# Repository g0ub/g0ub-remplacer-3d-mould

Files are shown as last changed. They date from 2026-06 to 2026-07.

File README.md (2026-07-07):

# REMPLACER — Agarose Mouse Brain Mould / Moule cerveau de souris en agarose

<p align="center">
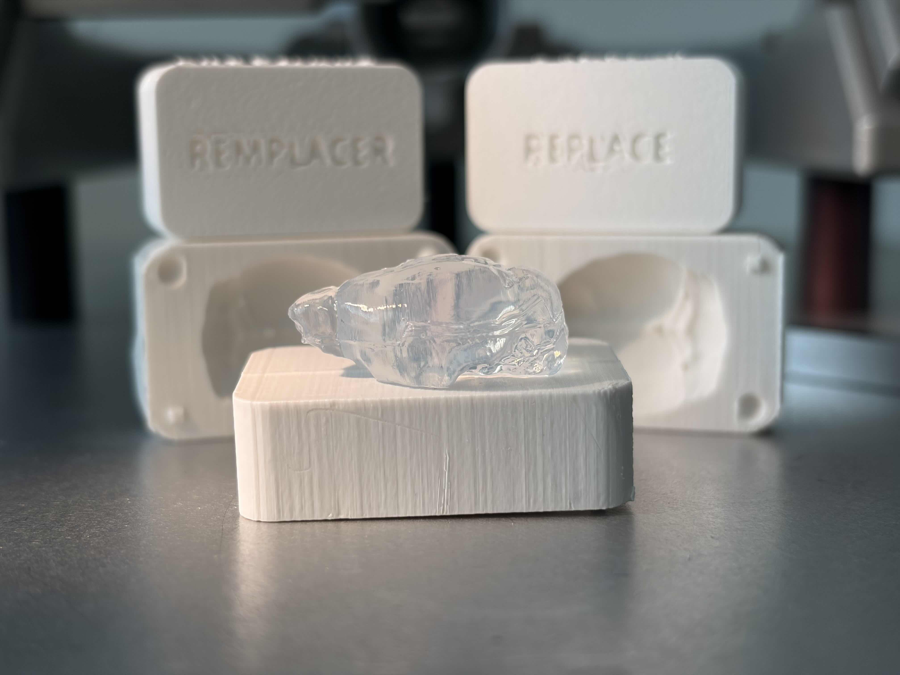
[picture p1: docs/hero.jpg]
REMPLACER / REPLACE printed mould halves with a freshly cast translucent agarose mouse brain in the foreground
  
</p>

**FR** | [EN below](#english-version)

---

## Version française

Ce dépôt contient les fichiers d'un moule en deux parties permettant de fabriquer des cerveaux de souris en **agarose**, utilisés dans l'atelier de médiation scientifique **REMPLACER** depuis 2017.

Le moule a été conçu à partir de **données anatomiques réelles de souris, librement accessibles en ligne**, et d'un générateur de moule paramétrique open source (voir [Sources & crédits](#sources--crédits)). Il permet de produire un modèle translucide utilisable avec un cadre stéréotaxique standard, **sans utiliser aucun animal**.

### ⬇️ Télécharger les moules

Fichiers STL prêts à imprimer (téléchargement direct) :

- **[Moule ×1,5](https://github.com/g0ub/g0ub-remplacer-3d-mould/releases/download/v1.0/mould_x1_5.stl)** — cerveau de souris adulte (~24 mm)
- **[Moule ×1,75](https://github.com/g0ub/g0ub-remplacer-3d-mould/releases/download/v1.0/mould_x1_75.stl)** — souris large / rat juvénile (~28 mm)
- **[Moule ×3](https://github.com/g0ub/g0ub-remplacer-3d-mould/releases/download/v1.0/mould_x3.stl)** — version atelier, braille tactile

Toutes les versions sont réunies sur la [page des releases](https://github.com/g0ub/g0ub-remplacer-3d-mould/releases). Pour explorer, modifier ou forker les fichiers source, voir le dossier [`/stl`](stl/) et le générateur OpenSCAD ([`scad/`](scad/)).

### 🙋 Vous avez utilisé ce moule ? Partagez vos retours !

Vous avez fabriqué des cerveaux en agarose pour votre labo, vos TP ou un atelier de médiation ? **Partagez votre expérience en ouvrant une [Issue](../../issues) sur ce dépôt** — photos, adaptations, retours de publics, versions modifiées du moule : tout est bienvenu. Si c'est plus simple, vous pouvez aussi écrire directement à : philippe.zizzari@inserm.fr.

Ces retours nous aident à améliorer le dispositif et à documenter son impact. Ils sont aussi précieux pour convaincre nos institutions de continuer à soutenir ce type de projet 🙂

> 🛠️ Si vous adaptez le moule, **merci de forker ce dépôt** plutôt que de redistribuer les fichiers séparément — cela préserve la traçabilité et permet à tout le monde de bénéficier des améliorations.

### Contenu du dépôt

```
/scad/
    mould_remplacer.scad   — source paramétrique (en-tête d'attribution inclus)
    mold_file.stl          — STL du cerveau aligné (importé par le .scad)
/stl/
    mould_x1_5.stl         — moule à ×1.5 (cerveau de souris adulte ~24 mm)
    mould_x1_75.stl        — moule à ×1.75 (souris large / rat juvénile ~28 mm)
    mould_x3.stl           — moule à ×3 (version atelier, braille tactile lisible)
/brain/
    README.md              — lien NITRC + notes de conversion .nii → STL (VTK)
/scripts/
    align_stl.py           — réoriente automatiquement un STL exporté de Slicer
PROTOCOL.md                — protocole de fabrication des cerveaux en agarose
CREDITS.md                 — attributions complètes (cerveau, Webb, rocketboy)
LICENSE                    — licence CC BY-NC-SA 4.0
```

> Le fichier de cerveau d'origine (`.nii`) **n'est pas redistribué ici**. En revanche, le STL pré-aligné (`/scad/mold_file.stl`) est inclus pour que le `.scad` compile directement après le clone — c'est aussi un dérivé du template NITRC, autorisé par sa licence CC BY-NC-SA. Voir le dossier [`/brain/`](brain/) si tu veux **régénérer** le STL depuis le `.nii` (par exemple pour un autre template, une autre espèce, ou pour adapter la résolution du maillage). Dans ce cas, fais-le passer par [`scripts/align_stl.py`](scripts/align_stl.py) avant de l'utiliser dans le `.scad` (voir [`brain/README.md`](brain/README.md) §3).

### Protocole rapide

1. Imprimer les deux parties du moule (PLA, résolution 0.2 mm recommandée)
2. Préparer une solution d'agarose à 1 à 2 % dans de l'eau distillée (1 % donne plus de translucidité, 2 % plus de tenue). **Astuce pratique** : verser la poudre dans l'eau, remuer, passer **30 s au micro-ondes** — ça dissout nickel. ⚠️ Le bord du bécher devient brûlant.
3. Fermer le moule en scotchant les deux parties sur la tranche, puis ajouter des bandes de scotch à 90° pour assurer l'étanchéité ; couler l'agarose encore chaud
4. Laisser polymériser ~15 min à température ambiante, puis ≥20 min à 4 °C (à ajuster selon vos conditions — **attendre vraiment** la polymérisation complète, c'est ce qui détermine la réussite du démoulage)
5. Démouler délicatement

### Impression et réglage des gravures

**Impression** — PLA, résolution 0.2 mm, remplissage 15–20 %. Les deux moitiés peuvent être imprimées face arrière sur le plateau (face avec le texte) : le texte apparaît bien net sur la première couche. Des supports sont nécessaires pour le canal de coulée et le braille (cf. [`PROTOCOL.md`](PROTOCOL.md) pour la procédure de *support blocker* dans la cuvette).

**Réglage des gravures** — toutes les valeurs sont paramétrables en haut du fichier [`scad/mould_remplacer.scad`](scad/mould_remplacer.scad) (bloc *Engraving parameters*) :

| Paramètre | Défaut | Rôle |
|---|---|---|
| `text_depth` | 1.2 mm | profondeur de gravure du texte REMPLACER / REPLACE |
| `text_size` | 9 mm | hauteur des lettres |
| `text_mirror_top` / `text_mirror_bottom` | `false` / `true` | si le texte apparaît en miroir une fois la pièce retournée, inverse |
| `braille_dot_d` | 1.5 mm | diamètre du point au contact (lisibilité tactile) |
| `braille_dot_h` | 0.75 mm | **hauteur du point qui dépasse** — indépendante du diamètre |
| `braille_dot_dist` | 2.5 mm | espacement entre points d'une cellule (norme Marburg) |
| `braille_cell_pitch` | 6.0 mm | espacement entre cellules (norme Marburg) |

> Le standard Marburg français pour le braille est d ≈ 1.5 mm et h ≈ 0.5 mm. La valeur par défaut de `braille_dot_h` est volontairement un peu plus haute (0.75 mm) pour compenser l'écrasement d'un point en PLA à 0.2 mm de couche. À ajuster selon ton imprimante : descends vers 0.5 mm si tes points ressortent trop pointus, monte vers 1 mm si on les sent à peine.

### En usage / In use

<p align="center">
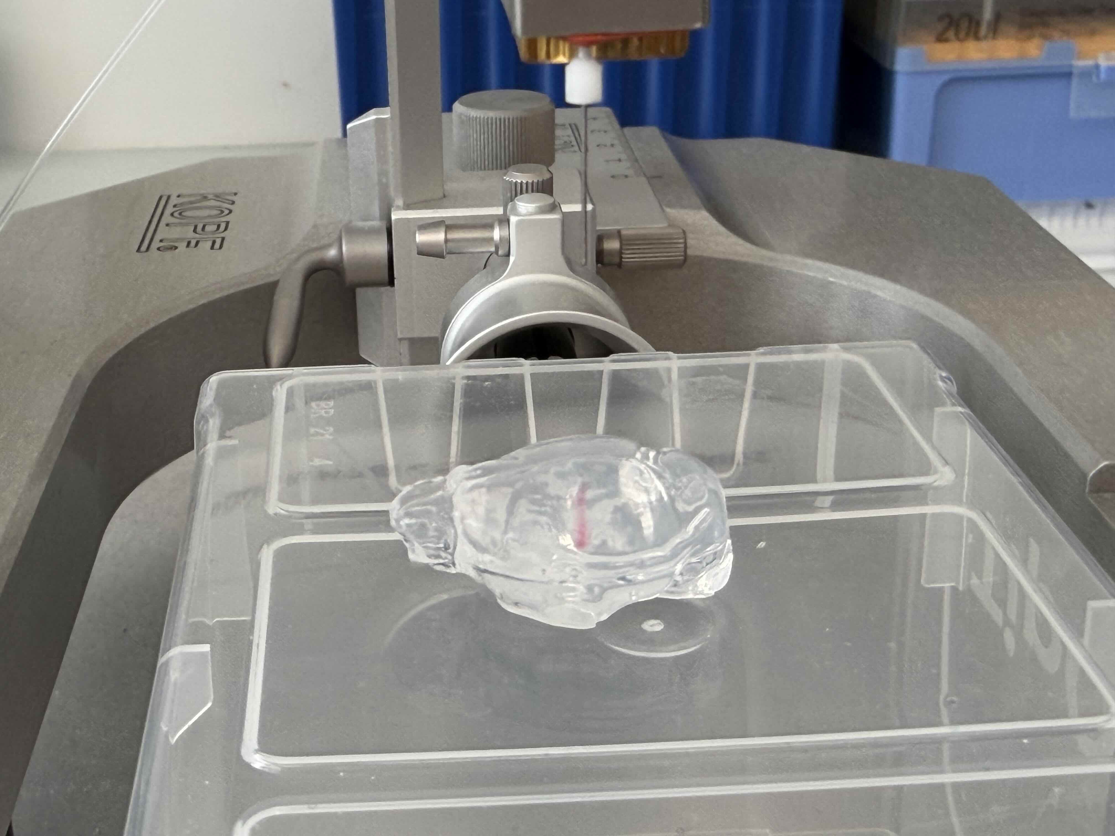
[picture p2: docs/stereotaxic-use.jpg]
Agarose mouse brain positioned in a Kopf stereotaxic frame with a visible injection trace inside the translucent gel
  
</p>

**🇫🇷** Cerveau en agarose moulé avec ce dispositif, positionné dans un cadre stéréotaxique standard. La trace rouge à l'intérieur du gel est une démonstration d'injection : le cerveau translucide permet de **voir en direct** la trajectoire de l'aiguille et le site de dépôt — un atout pédagogique central pour la formation en chirurgie stéréotaxique.

**🇬🇧** Agarose brain cast with this device, mounted in a standard stereotaxic frame. The red trace inside the gel is a demonstration injection: the translucent brain lets you **see in real time** the needle trajectory and the deposition site — a key teaching advantage for stereotaxic surgery training.

### Sources & crédits

Ce moule est un **travail dérivé**. Il réunit :

- le template anatomique de cerveau de souris C57BL/6 de **Hikishima et al. (2017)**, via NITRC (*tpm_mouse*), converti de NIfTI en STL ;
- le générateur de moule paramétrique en deux parties de **Jason Webb**, dans la version modifiée par **Dan Steele (rocketboy)** ;
- mes propres ajouts : positionnement du cerveau, canal de coulée oblique aligné sur le tronc cérébral, textes **REMPLACER / REPLACE** et leur transcription en **braille**.

La liste complète — liens, licences de chaque maillon et **citation à utiliser** — est dans [`CREDITS.md`](CREDITS.md). Merci de la conserver en cas de réutilisation.

### Licence

Ce travail est mis à disposition sous licence [Creative Commons Attribution — Pas d'Utilisation Commerciale — Partage dans les Mêmes Conditions 4.0 International (CC BY-NC-SA 4.0)](https://creativecommons.org/licenses/by-nc-sa/4.0/).

**En résumé :** vous pouvez utiliser, adapter et redistribuer ces fichiers librement, à condition de **citer les auteurs** (voir [`CREDITS.md`](CREDITS.md)), de **ne pas en faire un usage commercial**, et de **partager vos adaptations sous la même licence**.

Cette licence est imposée par le template de cerveau amont (CC BY-NC-SA) dont la géométrie est dérivée.

> 📝 **À titre personnel** — Ce dépôt et son contenu sont publiés à titre personnel par l'auteur. Les opinions, choix techniques et engagements qui y sont exprimés n'engagent que lui et ne reflètent pas nécessairement la position de l'INSERM ni de l'Université de Bordeaux. Les affiliations sont mentionnées à titre informatif uniquement.

**Auteur :** Philippe Zizzari — Ingénieur de Recherche, INSERM U1215, Neurocentre Magendie, Université de Bordeaux
**Contact :** philippe.zizzari@inserm.fr
**Site du projet :** [https://g0ub.github.io/remplacer/](https://g0ub.github.io/remplacer/)

---

## English version

This repository contains a two-part mould for casting **agarose** mouse brain models, used in the **REMPLACER** science outreach workshop since 2017.

The mould was designed from **real mouse anatomical data, freely available online**, together with an open-source parametric mould generator (see [Sources & credits](#sources--credits)). It produces a translucent model usable with a standard stereotaxic frame — **no animals required**.

### ⬇️ Download the moulds

Ready-to-print STL files (direct download):

- **[Mould ×1.5](https://github.com/g0ub/g0ub-remplacer-3d-mould/releases/download/v1.0/mould_x1_5.stl)** — adult mouse brain (~24 mm)
- **[Mould ×1.75](https://github.com/g0ub/g0ub-remplacer-3d-mould/releases/download/v1.0/mould_x1_75.stl)** — large mouse / juvenile rat (~28 mm)
- **[Mould ×3](https://github.com/g0ub/g0ub-remplacer-3d-mould/releases/download/v1.0/mould_x3.stl)** — workshop version, tactile braille

All versions are on the [releases page](https://github.com/g0ub/g0ub-remplacer-3d-mould/releases). To browse, modify or fork the source files, see the [`/stl`](stl/) folder and the OpenSCAD generator ([`scad/`](scad/)).

### 🙋 Have you used this mould? Share your feedback!

Have you cast agarose brains for your lab, teaching practicals, or an outreach event? **Open an [Issue](../../issues) to share your experience** — photos, adaptations, audience feedback, modified versions of the mould: all welcome. If it's easier, you can also reach us directly by email: philippe.zizzari@inserm.fr.

Your feedback helps us improve the device and document its reach. It also helps make the case to our institutions for continuing to support this kind of project 🙂

> 🛠️ If you adapt the mould, **please fork this repository** rather than redistributing the files separately — this preserves traceability and lets everyone benefit from improvements.

### Repository contents

```
/scad/
    mould_remplacer.scad   — parametric source (attribution header included)
    mold_file.stl          — aligned brain STL (imported by the .scad)
/stl/
    mould_x1_5.stl         — mould at ×1.5 (adult mouse brain, ~24 mm)
    mould_x1_75.stl        — mould at ×1.75 (large mouse / juvenile rat, ~28 mm)
    mould_x3.stl           — mould at ×3 (workshop version, tactile braille)
/brain/
    README.md              — NITRC link + .nii → STL conversion notes (VTK)
/scripts/
    align_stl.py           — automatically re-orients an STL exported from Slicer
PROTOCOL.md                — agarose brain casting protocol
CREDITS.md                 — full attribution chain (brain, Webb, rocketboy)
LICENSE                    — CC BY-NC-SA 4.0 licence
```

> The original brain file (`.nii`) is **not redistributed here**. However, the pre-aligned STL (`/scad/mold_file.stl`) is included so the `.scad` compiles right after cloning — it is itself a derivative of the NITRC template, permitted by its CC BY-NC-SA licence. See the [`/brain/`](brain/) folder if you want to **regenerate** the STL from the `.nii` (e.g. for a different template, a different species, or to tweak the mesh resolution). In that case, pass it through [`scripts/align_stl.py`](scripts/align_stl.py) before plugging it into the `.scad` (see [`brain/README.md`](brain/README.md) §3).

### Quick protocol

1. Print both mould halves (PLA, 0.2 mm resolution recommended)
2. Prepare a 1-2% agarose solution in distilled water (1% gives more translucency, 2% holds its shape better). **Practical tip**: pour the powder into the water, stir, then microwave for **30 s** — dissolves perfectly. ⚠️ The beaker rim gets very hot.
3. Close the mould by taping the two halves along the seam, then add strips of tape at 90° to seal it; pour the agarose while still hot
4. Let it set for ~15 min at room temperature, then ≥20 min at 4 °C (adjust to your conditions — **really wait** for full polymerization, this is what makes the demoulding succeed)
5. Demould carefully

### Printing & tuning the engravings

**Printing** — PLA, 0.2 mm resolution, 15–20 % infill. Both halves can be printed back face on the bed (the face that carries the text): the text comes out crisp on the first layer. Supports are needed on the pour channel and the braille (see [`PROTOCOL.md`](PROTOCOL.md) for the *support blocker* procedure inside the brain cavity).

**Tuning the engravings** — all values are parameterized at the top of [`scad/mould_remplacer.scad`](scad/mould_remplacer.scad) (block *Engraving parameters*):

| Parameter | Default | Role |
|---|---|---|
| `text_depth` | 1.2 mm | engraving depth of the REMPLACER / REPLACE text |
| `text_size` | 9 mm | letter height |
| `text_mirror_top` / `text_mirror_bottom` | `false` / `true` | flip if the text reads mirrored once the part is turned over |
| `braille_dot_d` | 1.5 mm | dot base diameter (tactile readability) |
| `braille_dot_h` | 0.75 mm | **dot height above the face** — independent of the diameter |
| `braille_dot_dist` | 2.5 mm | spacing between dots in a cell (Marburg standard) |
| `braille_cell_pitch` | 6.0 mm | spacing between cells (Marburg standard) |

> The French Marburg braille standard is d ≈ 1.5 mm and h ≈ 0.5 mm. The default `braille_dot_h` is set slightly higher (0.75 mm) to compensate for dot flattening in PLA at 0.2 mm layer height. Tune it to your printer: lower to 0.5 mm if the dots come out too pointy, raise to 1 mm if they're barely tactile.

### Sources & credits

This mould is a **derivative work**. It combines:

- the C57BL/6 mouse brain anatomical template by **Hikishima et al. (2017)**, via NITRC (*tpm_mouse*), converted from NIfTI to STL;
- the parametric two-part mould generator by **Jason Webb**, in the version modified by **Dan Steele (rocketboy)**;
- my own additions: brain positioning, an oblique pour channel aligned on the brainstem, and **REMPLACER / REPLACE** text with its **braille** transcription.

The full list — links, the licence of each layer, and the **citation to use** — is in [`CREDITS.md`](CREDITS.md). Please keep it when reusing.

### Licence

This work is licensed under [Creative Commons Attribution — NonCommercial — ShareAlike 4.0 International (CC BY-NC-SA 4.0)](https://creativecommons.org/licenses/by-nc-sa/4.0/).

**In short:** you may use, adapt and redistribute these files freely, provided you **credit the authors** (see [`CREDITS.md`](CREDITS.md)), make **no commercial use**, and **share any adaptations under the same licence**.

This licence is required by the upstream brain template (CC BY-NC-SA) from which the geometry is derived.

> 📝 **Personal capacity** — This repository and its contents are published by the author in a personal capacity. The opinions, technical choices and commitments expressed here are his own and do not necessarily reflect the position of INSERM or the University of Bordeaux. Affiliations are mentioned for information only.

**Author:** Philippe Zizzari — Research Engineer, INSERM U1215, Neurocentre Magendie, Université de Bordeaux
**Contact:** philippe.zizzari@inserm.fr
**Project website:** [https://g0ub.github.io/remplacer/](https://g0ub.github.io/remplacer/)

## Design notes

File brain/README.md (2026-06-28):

# `/brain/` — Anatomical model source & `.nii → STL` conversion / Source du modèle anatomique & conversion `.nii → STL`

**FR** | [EN below](#english-version)

---

## Version française

Ce dossier **ne contient pas** le fichier de cerveau d'origine : il explique
comment le récupérer à la source et reproduire la conversion en STL.
La licence du template (CC BY-NC-SA) autorise le re-hébergement, mais renvoyer
vers NITRC évite la duplication et garde l'attribution propre.

---

## ⚠️ Pièges courants (à lire en premier)

Trois bugs reviennent systématiquement quand on enchaîne Slicer → STL → OpenSCAD.
Ils font perdre du temps mais sont triviaux à éviter une fois connus.

1. **Toujours cliquer « Apply » dans Segment Editor avant l'export STL.**
   L'outil *Threshold* affiche un aperçu coloré séduisant, mais tant que
   tu n'as pas appuyé sur **Apply** en bas du panneau, le segment reste
   vide et l'export produit un STL vide.

2. **Cocher *Smoothing* + *Islands* dans Segment Editor avant l'export.**
   Sans ça, le STL contient souvent quelques vertices isolés (artéfacts de
   seuillage) qui peuvent perturber les outils en aval. Le script
   d'alignement les gère, mais autant les éviter dès la source.

3. **Fermer et rouvrir OpenSCAD à chaque fois qu'on modifie un STL externe.**
   OpenSCAD met les `import()` en cache et continue à utiliser l'ancienne
   version même si tu remplaces le fichier sur le disque. Si tu observes
   un comportement « impossible » (le moule semble correct alors que tu
   as cassé le STL exprès), c'est ça : ferme l'application et rouvre-la
   pour purger le cache.

---

## 1. Récupérer le template (NITRC)

> ℹ️ **Pour un usage rapide, c'est déjà fait.** Un STL du cerveau aligné est
> inclus dans le dépôt à [`/scad/mold_file.stl`](../scad/) et utilisé
> directement par le `.scad`. Les instructions ci-dessous décrivent comment
> **régénérer** ce STL depuis la source — utile pour un autre template, une
> autre espèce, ou pour adapter la résolution / le lissage du maillage.

- **Projet** : Templates for In vivo Mouse Brain (*tpm_mouse*)
- **URL** : https://www.nitrc.org/projects/tpm_mouse
- **Archive** : `C57Bl6.zip`
- **Fichier utilisé** : `Template_C57Bl6_T2_n10_brain.nii`
- **Licence** : CC BY-NC-SA — **citation obligatoire** :

  > Hikishima K, Komaki Y, Seki F, Ohnishi Y, Okano HJ, Okano H.
  > *In vivo microscopic voxel-based morphometry with a brain template to
  > characterize strain-specific structures in the mouse brain.*
  > Sci Rep. 2017;7(1):85. doi:10.1038/s41598-017-00148-1. PMID: 28273899.

> ⚠️ **Échelle** : sur ces templates, la taille des voxels a été
> **multipliée par 10** (pour un usage direct dans SPM). Le STL obtenu fait
> donc ~10× la taille réelle (~160 mm de long). C'est normal — la mise à
> l'échelle finale est gérée dans le `.scad` via le paramètre `model_scale`
> (≈ 0.10). Ne redimensionne pas le STL avant.

---

## 2. Convertir `.nii → STL` avec 3D Slicer (voie recommandée)

C'est la voie réellement utilisée pour ce moule. Tout se fait en interface
graphique, sans script.

1. **Charger le volume** — *File → Add Data…*, sélectionne
   `Template_C57Bl6_T2_n10_brain.nii`, *OK*.

2. **Créer un segment** — ouvre le module **Segment Editor**
   (*Modules → Segmentation → Segment Editor*). Clique **Add** pour créer un
   segment, donne-lui un nom (par ex. `brain`).

3. **Seuiller** — sélectionne l'outil **Threshold**. Glisse le curseur
   du seuil inférieur jusqu'à ce que **seule la surface du cerveau** soit
   colorée en aperçu (sans le crâne ni le bruit autour). Bascule en vue 3D
   pour vérifier. **Clique sur Apply** (cf. pièges courants §1).

4. **Lisser** *(recommandé)* — active l'outil **Smoothing**, méthode
   *Gaussian* ou *Median*, intensité modérée, *Apply*.

5. **Retirer les îlots flottants** *(recommandé)* — active l'outil
   **Islands**, opération *Keep largest island*, *Apply*. Cela élimine
   les vertices baladeurs qui sortiraient sinon dans le STL.

6. **Exporter en STL** — tout en bas du panneau Segment Editor, clique
   **Export to files…** :
   - *Destination folder* : choisis ton dossier
   - *File format* : **STL**
   - *Reference volume* : laisse par défaut
   - Coche le segment du cerveau dans la liste
   - **Export**

7. **Vérifier le STL** — ouvre-le dans PrusaSlicer, Cura ou MeshLab :
   - un seul objet (pas de bouts de crâne ou de bruit autour)
   - longueur ~160 mm (rappel : échelle ×10)
   - maillage étanche *(watertight)* — sinon, fais un *Repair* dans
     PrusaSlicer.

### Alternative : modèle intermédiaire

Si tu veux passer par un *Model node* exportable séparément (utile si tu
veux le manipuler avant l'export), tu peux d'abord convertir la
segmentation en modèle via *Segmentations → Export/import models and
labelmaps → Operation: Export, Output type: Models, Output node: Create
new model*. Slicer écrit le modèle d'abord en `.vtk` (son format natif) ;
tu peux ensuite le ré-ouvrir et le ré-exporter en STL (voir §4).

---

## 3. Aligner le STL pour le `.scad` (script Python)

Le `.scad` attend le cerveau dans une orientation précise (axe principal sur Z,
dorso-ventral sur Y, médio-latéral sur X). Selon ta version de Slicer et la
convention NIfTI du template, ton STL peut sortir orienté différemment — et
alors le moule **se forme vide ou bizarre**. Le script `scripts/align_stl.py`
analyse le STL et le réoriente automatiquement.

### Quand l'utiliser
Toujours, par sécurité. Coût : 2 secondes d'exécution, et tu as la garantie
que le moule sera bien formé. Si tu sais que ton STL est déjà dans la bonne
convention (par exemple parce que tu repars d'un export précédent qui
marchait), tu peux sauter cette étape.

### Installation
```
pip install trimesh numpy
```
(une seule fois, dépendances légères)

### Usage
```
python scripts/align_stl.py brain.stl
```
Le script écrit `brain_aligned.stl` à côté du STL d'entrée et affiche un
rapport détaillé. **Garde ce rapport sous les yeux**, il contient les
coordonnées à coller dans le `.scad` pour le canal de coulée.

### Options
- `--flip-ap` : force le retournement antéro-postérieur (à utiliser si
  l'auto-détection se trompe, c'est-à-dire si les bulbes olfactifs se
  retrouvent côté tronc dans le moule)
- `--flip-dv` : force le retournement dorso-ventral (rare ; la PCA ne
  peut pas distinguer dorsal et ventral toute seule)
- `--report` : génère juste le rapport sans écrire de fichier
- `-o sortie.stl` : choisir le nom du STL de sortie

### Brancher le STL aligné dans le `.scad`
1. Renomme `brain_aligned.stl` en `mold_file.stl` (ou modifie
   `model_filename` dans le `.scad`).
2. **Ferme et rouvre OpenSCAD** (cf. pièges courants §3).
3. Le rapport du script propose **deux options** pour les coordonnées
   du canal de coulée (`bs_tip` / `bs_entry`), parce que l'orientation
   antéro/postérieure peut tomber dans un sens ou dans l'autre. Copie
   d'abord l'**Option A** dans le `.scad` :
   ```scad
   bs_tip   = [ ..., ..., ... ];
   bs_entry = [ ..., ..., ... ];
   ```
4. Mets `show_brain_debug = true;` dans le `.scad` et fais F5.
5. Vérification visuelle :
   - **sphère rouge sur le tronc cérébral** (cervelet ventral) → garde l'Option A ✓
   - **sphère rouge sur les bulbes olfactifs** → remplace par l'Option B, F5
6. Repasse `show_brain_debug = false;` et vérifie que le moule se forme
   correctement avec le canal de coulée à l'endroit attendu.

Pour un réglage très fin de la position du canal, tu peux éditer
`bs_tip` / `bs_entry` à la main : les sphères rouge (`bs_tip`) et bleue
(`bs_entry`) se déplacent dans la vue debug et tu vois en direct où elles
tombent par rapport au tronc.

### Cas particulier : STL avec plusieurs objets
Le script attend **un seul cerveau** dans le STL. Si ton STL contient
plusieurs objets (cerveau + restes de crâne, deux cerveaux superposés
après une manipulation Blender, etc.), nettoie-le d'abord dans PrusaSlicer
(*clic droit → Split → To objects*, supprimer ce qui n'est pas le cerveau,
*Export STL*).

---

## 4. Convertir `.nii → STL` en Python avec VTK (option scriptée)

Pour automatiser ou reproduire le pipeline dans un script, voici
l'équivalent du seuillage + extraction d'isosurface fait par Slicer :

```python
# pip install vtk
import vtk

IN_FILE  = "Template_C57Bl6_T2_n10_brain.nii"
OUT_FILE = "brain.stl"
ISO      = 0.5          # seuil — à régler (voir ci-dessous)

# 1. Lecture du NIfTI
reader = vtk.vtkNIFTIImageReader()
reader.SetFileName(IN_FILE)
reader.Update()

# 2. (option) léger lissage du volume avant l'extraction
gauss = vtk.vtkImageGaussianSmooth()
gauss.SetInputConnection(reader.GetOutputPort())
gauss.SetStandardDeviations(1.0, 1.0, 1.0)
gauss.Update()

# 3. Isosurface (marching cubes / flying edges)
mc = vtk.vtkFlyingEdges3D()
mc.SetInputConnection(gauss.GetOutputPort())
mc.SetValue(0, ISO)
mc.Update()

# 4. Garder uniquement la plus grande région connexe (enlève le bruit)
conn = vtk.vtkPolyDataConnectivityFilter()
conn.SetInputConnection(mc.GetOutputPort())
conn.SetExtractionModeToLargestRegion()
conn.Update()

# 5. Lissage + allègement du maillage pour l'impression
smooth = vtk.vtkWindowedSincPolyDataFilter()
smooth.SetInputConnection(conn.GetOutputPort())
smooth.SetNumberOfIterations(20)
smooth.BoundarySmoothingOff()
smooth.NonManifoldSmoothingOn()
smooth.NormalizeCoordinatesOn()
smooth.Update()

deci = vtk.vtkDecimatePro()
deci.SetInputConnection(smooth.GetOutputPort())
deci.SetTargetReduction(0.5)   # ~50 % de triangles en moins
deci.PreserveTopologyOn()
deci.Update()

# 6. Écriture STL (binaire)
writer = vtk.vtkSTLWriter()
writer.SetFileName(OUT_FILE)
writer.SetInputConnection(deci.GetOutputPort())
writer.SetFileTypeToBinary()
writer.Write()
print("written:", OUT_FILE)
```

### Régler le seuil `ISO`
La valeur dépend de l'intensité du volume. Le plus simple est de la
trouver visuellement **dans 3D Slicer** avec l'outil *Threshold* (la
valeur basse du curseur, quand seule la surface du cerveau est isolée),
puis de la reporter dans le script.

Le STL produit par ce script Python doit ensuite passer par
`scripts/align_stl.py` (§3), comme un STL Slicer.

---

## 5. Convertir un `.vtk` existant en `.stl`

Si tu as exporté depuis 3D Slicer en `.vtk` (format natif de Slicer) et
que tu veux passer en `.stl`, trois options :

- **Le plus simple** : ré-ouvrir le `.vtk` dans Slicer (*File → Add
  Data…*), puis l'exporter en STL via la même procédure qu'au §2
  (clic droit *Export to file…* sur le modèle, ou *File → Save Data…* en
  choisissant **STL** dans la colonne *File Format*).
- **Sans Slicer** : *File → Import Mesh* dans **MeshLab**, puis
  *File → Export Mesh As… → STL*.
- **En script Python avec VTK** :

  ```python
  import vtk
  reader = vtk.vtkPolyDataReader()       # ou vtkXMLPolyDataReader() pour .vtp
  reader.SetFileName("brain.vtk")
  reader.Update()
  writer = vtk.vtkSTLWriter()
  writer.SetFileName("brain.stl")
  writer.SetInputConnection(reader.GetOutputPort())
  writer.SetFileTypeToBinary()
  writer.Write()
  ```

  Le format VTK existe en deux variantes — *legacy* (`.vtk`,
  `vtkPolyDataReader`) et *XML* (`.vtp`, `vtkXMLPolyDataReader`).
  Ouvre le fichier avec un éditeur de texte pour t'en assurer : le legacy
  commence par `# vtk DataFile Version`.

---

## English version

This folder **does not contain** the original brain file: it explains how to
fetch it from the source and reproduce the STL conversion. The template's
licence (CC BY-NC-SA) allows re-hosting, but pointing back to NITRC avoids
duplication and keeps attribution clean.

---

## ⚠️ Common pitfalls (read first)

Three bugs come up systematically along the Slicer → STL → OpenSCAD pipeline.
They waste time but are trivial to avoid once known.

1. **Always click "Apply" in Segment Editor before exporting the STL.**
   The *Threshold* tool shows a tempting coloured preview, but until you
   press **Apply** at the bottom of the panel, the segment stays empty and
   the export produces an empty STL.

2. **Tick *Smoothing* + *Islands* in Segment Editor before exporting.**
   Without these, the STL often contains a few stray vertices (thresholding
   artefacts) that can confuse downstream tools. The alignment script handles
   them, but it's better to avoid them at the source.

3. **Close and reopen OpenSCAD every time you modify an external STL.**
   OpenSCAD caches `import()` and keeps using the old version even when
   you replace the file on disk. If you see "impossible" behaviour (the mould
   looks correct even though you deliberately broke the STL), this is why:
   close the app and reopen it to flush the cache.

---

## 1. Fetch the template (NITRC)

> ℹ️ **For a quick start, this is already done.** An aligned brain STL is
> bundled in the repository at [`/scad/mold_file.stl`](../scad/) and used
> directly by the `.scad`. The instructions below describe how to
> **regenerate** that STL from source — useful for a different template,
> a different species, or to tune the mesh resolution / smoothing.

- **Project**: Templates for In vivo Mouse Brain (*tpm_mouse*)
- **URL**: https://www.nitrc.org/projects/tpm_mouse
- **Archive**: `C57Bl6.zip`
- **File used**: `Template_C57Bl6_T2_n10_brain.nii`
- **Licence**: CC BY-NC-SA — **citation required**:

  > Hikishima K, Komaki Y, Seki F, Ohnishi Y, Okano HJ, Okano H.
  > *In vivo microscopic voxel-based morphometry with a brain template to
  > characterize strain-specific structures in the mouse brain.*
  > Sci Rep. 2017;7(1):85. doi:10.1038/s41598-017-00148-1. PMID: 28273899.

> ⚠️ **Scale**: on these templates, the voxel size has been **multiplied by 10**
> (for direct use in SPM). The resulting STL is therefore ~10× life size
> (~160 mm long). That's expected — final scaling is handled inside the
> `.scad` via the `model_scale` parameter (≈ 0.10). Don't resize the STL
> beforehand.

---

## 2. Convert `.nii → STL` with 3D Slicer (recommended path)

This is the path actually used for this mould. Everything happens in the
graphical interface, no scripting needed.

1. **Load the volume** — *File → Add Data…*, select
   `Template_C57Bl6_T2_n10_brain.nii`, *OK*.

2. **Create a segment** — open the **Segment Editor** module
   (*Modules → Segmentation → Segment Editor*). Click **Add** to create a
   segment, name it (e.g. `brain`).

3. **Threshold** — select the **Threshold** tool. Slide the lower threshold
   until **only the surface of the brain** is highlighted in the preview
   (no skull or noise around). Switch to 3D view to confirm. **Click Apply**
   (see common pitfalls §1).

4. **Smooth** *(recommended)* — activate the **Smoothing** tool, method
   *Gaussian* or *Median*, moderate intensity, *Apply*.

5. **Remove floating islands** *(recommended)* — activate the **Islands**
   tool, operation *Keep largest island*, *Apply*. This eliminates the stray
   vertices that would otherwise show up in the STL.

6. **Export as STL** — at the bottom of the Segment Editor panel, click
   **Export to files…**:
   - *Destination folder*: choose your folder
   - *File format*: **STL**
   - *Reference volume*: leave default
   - Tick the brain segment in the list
   - **Export**

7. **Sanity-check the STL** — open it in PrusaSlicer, Cura or MeshLab:
   - a single object (no skull fragments or noise around)
   - length ~160 mm (remember: ×10 scale)
   - watertight mesh — if not, use *Repair* in PrusaSlicer.

### Alternative: via an intermediate model

If you want to go through a separately exportable *Model node* (useful for
manipulating the model before export), you can first convert the segmentation
to a model via *Segmentations → Export/import models and labelmaps →
Operation: Export, Output type: Models, Output node: Create new model*.
Slicer first writes the model as `.vtk` (its native format); you can then
reopen and re-export it as STL (see §4).

---

## 3. Align the STL for the `.scad` (Python script)

The `.scad` expects the brain in a specific orientation (principal axis on Z,
dorso-ventral on Y, medio-lateral on X). Depending on your Slicer version and
on the NIfTI template's convention, your STL may come out oriented differently
— and then the mould **prints empty or weird**. The `scripts/align_stl.py`
script analyses the STL and re-orients it automatically.

### When to use it
Always, for safety. Cost: a 2-second run, and you have the guarantee the mould
will be properly formed. If you know your STL is already in the right
convention (because you reused a previous working export, for example), you
can skip this step.

### Install
```
pip install trimesh numpy
```
(one time only, lightweight dependencies)

### Usage
```
python scripts/align_stl.py brain.stl
```
The script writes `brain_aligned.stl` next to the input STL and prints a
detailed report. **Keep this report at hand**, it contains the coordinates
you need to paste into the `.scad` for the pour channel.

### Options
- `--flip-ap`: force an antero-posterior flip (use this if the auto-detection
  gets it wrong, i.e. if the olfactory bulbs end up on the brainstem side
  in the mould)
- `--flip-dv`: force a dorso-ventral flip (rare; PCA cannot tell dorsal
  from ventral on its own)
- `--report`: print only the diagnostic report, do not write any file
- `-o output.stl`: choose the output STL filename

### Plug the aligned STL into the `.scad`
1. Rename `brain_aligned.stl` to `mold_file.stl` (or change `model_filename`
   in the `.scad`).
2. **Close and reopen OpenSCAD** (see common pitfalls §3).
3. The script's report proposes **two options** for the pour-channel
   coordinates (`bs_tip` / `bs_entry`), because the antero-posterior
   orientation may fall either way. Paste **Option A** into the `.scad`
   first:
   ```scad
   bs_tip   = [ ..., ..., ... ];
   bs_entry = [ ..., ..., ... ];
   ```
4. Set `show_brain_debug = true;` in the `.scad` and press F5.
5. Visual check:
   - **red sphere on the brainstem** (ventral cerebellum) → keep Option A ✓
   - **red sphere on the olfactory bulbs** → replace with Option B, F5
6. Set `show_brain_debug = false;` again and check the mould forms correctly
   with the pour channel where expected.

For fine-tuning the channel position, you can edit `bs_tip` / `bs_entry`
by hand: the red sphere (`bs_tip`) and blue sphere (`bs_entry`) move in
the debug view so you see live where they land on the brainstem.

### Special case: STL with several objects
The script expects **a single brain** in the STL. If your STL contains
multiple objects (brain + skull fragments, two overlapping brains after
some Blender manipulation, etc.), clean it first in PrusaSlicer (*right-click
→ Split → To objects*, delete what is not the brain, *Export STL*).

---

## 4. Convert `.nii → STL` in Python with VTK (scripted option)

To automate the pipeline in a script, here is the Python equivalent of the
thresholding + isosurface extraction that Slicer does:

```python
# pip install vtk
import vtk

IN_FILE  = "Template_C57Bl6_T2_n10_brain.nii"
OUT_FILE = "brain.stl"
ISO      = 0.5          # threshold — tune (see below)

# 1. Read the NIfTI
reader = vtk.vtkNIFTIImageReader()
reader.SetFileName(IN_FILE)
reader.Update()

# 2. (optional) light volume smoothing before extraction
gauss = vtk.vtkImageGaussianSmooth()
gauss.SetInputConnection(reader.GetOutputPort())
gauss.SetStandardDeviations(1.0, 1.0, 1.0)
gauss.Update()

# 3. Isosurface (marching cubes / flying edges)
mc = vtk.vtkFlyingEdges3D()
mc.SetInputConnection(gauss.GetOutputPort())
mc.SetValue(0, ISO)
mc.Update()

# 4. Keep only the largest connected region (removes noise)
conn = vtk.vtkPolyDataConnectivityFilter()
conn.SetInputConnection(mc.GetOutputPort())
conn.SetExtractionModeToLargestRegion()
conn.Update()

# 5. Smoothing + mesh simplification for printing
smooth = vtk.vtkWindowedSincPolyDataFilter()
smooth.SetInputConnection(conn.GetOutputPort())
smooth.SetNumberOfIterations(20)
smooth.BoundarySmoothingOff()
smooth.NonManifoldSmoothingOn()
smooth.NormalizeCoordinatesOn()
smooth.Update()

deci = vtk.vtkDecimatePro()
deci.SetInputConnection(smooth.GetOutputPort())
deci.SetTargetReduction(0.5)   # ~50 % fewer triangles
deci.PreserveTopologyOn()
deci.Update()

# 6. Write STL (binary)
writer = vtk.vtkSTLWriter()
writer.SetFileName(OUT_FILE)
writer.SetInputConnection(deci.GetOutputPort())
writer.SetFileTypeToBinary()
writer.Write()
print("written:", OUT_FILE)
```

### Tuning the `ISO` threshold
The value depends on the volume's intensity. The easiest is to find it
visually **in 3D Slicer** with the *Threshold* tool (the lower value of the
slider when only the brain surface is isolated), then transfer it to the
script.

The STL produced by this Python script must then go through
`scripts/align_stl.py` (§3), like any Slicer STL.

---

## 5. Convert an existing `.vtk` to `.stl`

If you exported from 3D Slicer in `.vtk` (Slicer's native format) and want
to switch to `.stl`, three options:

- **The easiest**: re-open the `.vtk` in Slicer (*File → Add Data…*), then
  export to STL via the same procedure as §2 (right-click *Export to file…*
  on the model, or *File → Save Data…* selecting **STL** in the *File Format*
  column).
- **Without Slicer**: *File → Import Mesh* in **MeshLab**, then
  *File → Export Mesh As… → STL*.
- **In a Python script with VTK**:

  ```python
  import vtk
  reader = vtk.vtkPolyDataReader()       # or vtkXMLPolyDataReader() for .vtp
  reader.SetFileName("brain.vtk")
  reader.Update()
  writer = vtk.vtkSTLWriter()
  writer.SetFileName("brain.stl")
  writer.SetInputConnection(reader.GetOutputPort())
  writer.SetFileTypeToBinary()
  writer.Write()
  ```

  The VTK format exists in two flavours — *legacy* (`.vtk`,
  `vtkPolyDataReader`) and *XML* (`.vtp`, `vtkXMLPolyDataReader`).
  Open the file in a text editor to check: the legacy variant starts with
  `# vtk DataFile Version`.

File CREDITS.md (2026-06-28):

# Crédits et attributions

Ce moule est un **travail dérivé** combinant plusieurs ressources ouvertes.
L'ensemble du dépôt est distribué sous licence **Creative Commons
Attribution – Pas d'Utilisation Commerciale – Partage dans les Mêmes
Conditions 4.0 International (CC BY-NC-SA 4.0)** — voir le fichier `LICENSE`.

Cette licence est imposée par le template de cerveau amont (NITRC tpm_mouse,
CC BY-NC-SA), dont la géométrie est dérivée : les clauses NC et SA se
propagent à l'ensemble de l'œuvre.

---

## 1. Modèle anatomique du cerveau

- **Fichier source** : `Template_C57Bl6_T2_n10_brain.nii`
- **Projet** : Templates for In vivo Mouse Brain (*tpm_mouse*), NITRC
- **URL** : https://www.nitrc.org/projects/tpm_mouse
- **Auteur / contact** : Keigo Hikishima (OIST)
- **Licence d'origine** : CC BY-NC-SA
- **Référence à citer** :
  > Hikishima K, Komaki Y, Seki F, Ohnishi Y, Okano HJ, Okano H.
  > *In vivo microscopic voxel-based morphometry with a brain template to
  > characterize strain-specific structures in the mouse brain.*
  > Sci Rep. 2017;7(1):85. doi:10.1038/s41598-017-00148-1. PMID: 28273899.
- **Étape réalisée** : conversion du fichier NIfTI (`.nii`) en maillage STL
  (pipeline via VTK), puis réorientation avec `scripts/align_stl.py`.
  Le STL résultant — inclus dans le dépôt à `/scad/mold_file.stl` — est
  un dérivé direct du template NITRC ; sa redistribution est autorisée par
  la licence CC BY-NC-SA d'origine, sous réserve du respect des clauses
  d'attribution (cf. citation ci-dessus), NC et SA.

---

## 2. Générateur de moule en deux parties (chaîne de dérivés)

### 2a. Auteur original
- **Script** : Parametric two-part mold generator for OpenSCAD
- **Auteur** : Jason Webb — https://jasonwebb.io
- **Source** : https://www.thingiverse.com/thing:31581 (publication d'origine, 2012)
- **Licence** : Creative Commons (voir la fiche Thingiverse d'origine) —
  dérivés autorisés et explicitement encouragés par l'auteur.

### 2b. Modification intermédiaire
- **Titre** : « Mold Generator - modified »
- **Auteur** : Dan Steele (*rocketboy* sur Thingiverse), 31 août 2014
- **Profil** : https://www.thingiverse.com/rocketboy
- **Source** : https://www.thingiverse.com/thing:447443
- **Licence d'origine** : CC BY (Creative Commons – Attribution)
- **Modifications** :
  - une clé de repérage transformée en cube, pour empêcher l'assemblage
    du moule à l'envers ;
  - trou de coulée optionnel.

### 2c. Adaptations REMPLACER (ce dépôt)
- **Auteur** : Philippe Zizzari — atelier REMPLACER,
  Neurocentre Magendie (INSERM U1215), 2026 — https://github.com/g0ub / https://g0ub.github.io/remplacer/
- **Modifications** :
  - import de la forme de cerveau (STL dérivé du template NITRC, cf. §1),
    positionnée et mise à l'échelle dans le moule ;
  - **canal de coulée OBLIQUE aligné sur le tronc cérébral** :
    - `module cone_between()` : cône conique le long d'un vecteur quelconque ;
    - canal défini dans le repère du STL (vise directement le tronc) ;
    - le canal débouche dans une seule moitié, par la face latérale du moule ;
  - ajout des textes **REMPLACER / REPLACE** et de leur transcription en
    **braille**.

---

## Licence de l'ensemble

Tous les fichiers de ce dépôt (STL dérivés du cerveau, source `.scad`,
textes et ajouts REMPLACER) sont publiés sous **CC BY-NC-SA 4.0**.
Toute réutilisation doit créditer l'ensemble de la chaîne ci-dessus,
rester non commerciale et conserver la même licence.

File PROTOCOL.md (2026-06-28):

# PROTOCOL — Cerveaux de souris en agarose / Agarose mouse-brain casting

**FR** | [EN below](#english-version)

> Les valeurs ci-dessous (concentration, temps de prise) sont des **points de
> départ** issus de la pratique de l'atelier REMPLACER. Ajustez-les à votre
> agarose, votre volume de moule et votre température ambiante.

---

## Version française

### Matériel
- Les deux moitiés du moule imprimées (`/stl/`)
- Agarose en poudre + eau distillée
- Récipient + chauffage (micro-ondes ou plaque chauffante)
- Ruban adhésif résistant (type scotch de bureau)
- Réfrigérateur (4 °C)

### Impression du moule
- Matériau : **PLA**
- Résolution : **0,2 mm** recommandée
- Remplissage : 15–20 % suffisent (les parois portent la forme)
- Orientation : face arrière (avec le texte REMPLACER/REPLACE) **sur le plateau**

#### Supports & blocker de support (PrusaSlicer)
Le moule a deux zones qui réclament des supports, et **une zone où il faut empêcher** le slicer d'en mettre :

- **Supports nécessaires** sur le **canal de coulée** (cône oblique, en surplomb) et sur le **braille en relief** (chaque point est un dôme sur une face verticale). Sans supports, ces zones impriment mal.
- **Bloqueur de support obligatoire** à l'intérieur de la **cuvette du cerveau** : par défaut, PrusaSlicer y détecte une instabilité et propose d'ajouter des supports, mais ceux-ci seraient piégés à l'intérieur du moule et abîmeraient l'empreinte au retrait. Place un *Support Blocker* qui recouvre toute la cuvette (clic droit sur l'objet → *Add modifier → Support Blocker → Box*, redimensionner pour couvrir la cuvette).

Avec ces réglages, le slicer met les supports uniquement là où il faut, et la cuvette reste lisse et propre.

### Préparation de l'agarose (1 à 2 %)
1. Peser **1 à 2 g d'agarose pour 100 mL** d'eau distillée (1 % donne plus de translucidité, 2 % plus de tenue).
2. Chauffer en remuant jusqu'à dissolution **complète et limpide** (proche de
   l'ébullition, sans déborder). La solution doit être parfaitement claire.

> **Pourquoi pas de colorant ?** Les colorants alimentaires et autres
> colorants histologiques classiques (éosine, etc.) diffusent au cours du
> temps : ils s'échappent du gel quand on conserve les cerveaux dans l'eau,
> et l'agarose redevient incolore. C'est aussi ce qui se passe à l'intérieur
> d'un cerveau en agarose quand on l'utilise pour visualiser une injection
> stéréotaxique au colorant alimentaire : le colorant diffuse du site
> d'injection vers tout le volume. Pour ce dernier usage, **l'encre de Chine**
> fonctionne mieux : les particules de carbone restent piégées dans le
> maillage de polysaccharides et permettent de visualiser de façon durable
> le site d'injection.

### Fermeture et coulée
1. Assembler les deux moitiés (les détrompeurs — clé cube — garantissent le
   bon sens).
2. **Sceller** : poser du ruban adhésif sur la tranche pour solidariser les
   deux parties, puis ajouter des bandes **à 90°** pour assurer l'étanchéité.
3. **Couler l'agarose encore chaud** par le trou de coulée, jusqu'à
   remplissage complet ; tapoter doucement pour chasser les bulles.

### Prise et démoulage
1. Laisser polymériser **~15 min à température ambiante**.
2. Puis **≥ 20 min à 4 °C** (le froid raffermit le gel et facilite le
   démoulage) — *à ajuster selon vos conditions*.
3. **Bien attendre** la polymérisation complète avant d'ouvrir le moule —
   c'est l'étape la plus importante pour réussir le démoulage. À 1 % d'agarose,
   le gel est très translucide mais aussi très fragile : ne pas précipiter.
4. Retirer le ruban, ouvrir délicatement les deux moitiés, démouler le cerveau.

### Conseils
- Un agarose mal dissous donne un gel trouble et fragile : insistez sur l'étape
  de chauffage.
- Bulles : couler lentement, mouler tiède, tapoter.
- Démoulage difficile : prolonger le passage à 4 °C, ou augmenter légèrement la
  concentration d'agarose pour un gel plus ferme.
- Le modèle peut être utilisé avec un **cadre stéréotaxique standard** pour
  les démonstrations.
- Conservation : **immergé dans l'eau du robinet** dans un contenant fermé.
  Le gel se dessèche à l'air libre. Pas besoin de réfrigérateur, mais
  **changer l'eau régulièrement** (toutes les 1 à 2 semaines) — sans ça,
  des algues peuvent se développer. Si ça arrive, un lavage des cerveaux à
  l'eau javellisée diluée permet souvent de les récupérer.

---

## English version

### Materials
- Both printed mould halves (`/stl/`)
- Agarose powder + distilled water
- Container + heat source (microwave or hot plate)
- Strong tape (office tape)
- Refrigerator (4 °C)

### Printing the mould
- Material: **PLA**
- Resolution: **0.2 mm** recommended
- Infill: 15–20 % is enough (the walls carry the shape)
- Orientation: back face (with the REMPLACER/REPLACE text) **on the bed**

#### Supports & support blocker (PrusaSlicer)
The mould has two areas that need supports, and **one area where you must prevent** the slicer from adding them:

- **Supports needed** on the **pour channel** (oblique cone, overhang) and on the **braille in relief** (each dot is a dome on a vertical face). Without supports these areas print badly.
- **Mandatory support blocker** inside the **brain cavity**: PrusaSlicer flags it as unstable and proposes to add supports, but they would be trapped inside the mould and would damage the imprint on removal. Place a *Support Blocker* covering the whole cavity (right-click the object → *Add modifier → Support Blocker → Box*, resize it to cover the cavity).

With these settings, the slicer adds supports only where they belong, and the cavity prints smooth and clean.

### Preparing the agarose (1 to 2 %)
1. Weigh **1 to 2 g agarose per 100 mL** distilled water (1 % gives more translucency, 2 % holds its shape better).
2. Heat while stirring until **fully and clearly dissolved** (near boiling,
   without boiling over). The solution must be perfectly clear.

> **Why no dye?** Food dyes and classical histological dyes (eosin, etc.)
> diffuse out over time: they leach from the gel when the brains are stored
> in water, and the agarose turns clear again. The same thing happens *inside*
> an agarose brain used to visualise stereotaxic injections with food dye:
> the dye diffuses from the injection site to the whole volume. For that
> purpose, **India ink** works much better: the carbon particles get trapped
> in the polysaccharide mesh and provide a durable visualisation of the
> injection site.

### Closing and pouring
1. Assemble both halves (the cube key prevents assembling them backwards).
2. **Seal**: tape along the seam to hold the halves together, then add strips
   **at 90°** to make it watertight.
3. **Pour the agarose while still hot** through the pour hole until full; tap
   gently to release bubbles.

### Setting and demoulding
1. Let it set for **~15 min at room temperature**.
2. Then **≥ 20 min at 4 °C** (chilling firms the gel and eases demoulding) —
   *adjust to your conditions*.
3. **Really wait** for full polymerization before opening the mould — this is
   the most important step for a successful demoulding. At 1 % agarose, the gel
   is very translucent but also very fragile: do not rush it.
4. Remove the tape, gently open the halves, demould the brain.

### Tips
- Poorly dissolved agarose gives a cloudy, fragile gel: don't rush the heating
  step.
- Bubbles: pour slowly, cast warm, tap the mould.
- Hard to demould: extend the 4 °C step, or slightly raise the agarose
  concentration for a firmer gel.
- The model can be used with a **standard stereotaxic frame** for demonstrations.
- Storage: **immersed in tap water** in a closed container. The gel dries
  out in open air. No need to refrigerate, but **change the water regularly**
  (every 1 to 2 weeks) — otherwise algae can grow. If that happens, washing
  the brains in dilute bleach water often saves them.

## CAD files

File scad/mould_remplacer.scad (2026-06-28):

/*************************************************************************
 REMPLACER — agarose mouse-brain mould
 Two-part parametric mould generator with an oblique brainstem pour channel

 -----------------------------------------------------------------------
 ATTRIBUTION CHAIN  (please keep intact — this is a derivative work)
 -----------------------------------------------------------------------
 Original author : Jason Webb
                   http://jason-webb.info  (now https://jasonwebb.io)
                   "Parametric two-part mold generator"
                   https://www.thingiverse.com/thing:31581  (2012)

 Modified by     : Dan Steele (rocketboy on Thingiverse) — licensed CC BY
                   "Mold Generator - modified"
                   https://www.thingiverse.com/thing:447443  (2014)
                   - one registration key changed to a cube so the mould
                     cannot be assembled backwards
                   - optional pour hole

 Modified again  : Philippe Zizzari — REMPLACER outreach workshop
                   INSERM U1215, Neurocentre Magendie, 2026
                   https://github.com/g0ub
                   - imports a mouse-brain STL derived from the NITRC
                     tpm_mouse C57BL/6 template (Hikishima et al. 2017,
                     CC BY-NC-SA), positioned and scaled inside the mould
                   - OBLIQUE pour channel aligned on the brainstem:
                       * cone_between(): conical channel along an
                         arbitrary vector
                       * channel defined in the STL's own frame
                         (aims straight at the brainstem)
                       * half-channel subtracted from EACH half, so the
                         two halves form a complete conduit when closed
                   - REMPLACER / REPLACE text engraved on the back of each
                     half (along the 80 mm axis), and "remplacer" in French
                     braille IN RELIEF on the long lateral face of the bottom
                     half (centered, Marburg pitch — see parameters at top)

 roundedBox()    : from OpenSCAD's bundled example022.scad (public domain)

 -----------------------------------------------------------------------
 LICENSE: CC BY-NC-SA 4.0
 The brain geometry derives from a CC BY-NC-SA template, so the
 NonCommercial + ShareAlike terms apply to this whole work.
 Full attribution & citation: see CREDITS.md.  License text: see LICENSE.
*************************************************************************/

/*************************************************
 Mould size
*************************************************/
// Global scale factor for the whole mould (and the brain inside).
// Three sizes are shipped: 1.5, 1.75 and 3.
// - 1.5  : close to an adult mouse brain
// - 1.75 : intermediate size (large mouse / juvenile rat)
// - 3    : workshop version — the only size at which the braille is
//          tactilely readable (standard Marburg pitch of 6 mm).
mould_size_factor = 3;

// Enable or disable the braille in relief.
// The braille is laid out in standard Marburg pitch (ABSOLUTE dimensions,
// NOT scaled with the mould). Below mould_size_factor = 3 it does not fit
// on the lateral face — it must then be disabled.
show_braille = (mould_size_factor >= 3);

// Model parameters
model_filename  = "mold_file.stl";
model_rotate    = [90, 0, 0];
model_scale     = 0.10 * mould_size_factor;   // brain ~16 mm at ×1 (STL ~161 mm)
model_translate = [0, 0, 25];                 // CONSTANT (do not scale with factor)

// Mould parameters — ×1 baseline multiplied by the factor.
// Baseline ×1 (per half): 12.5 × 20 × 6.25 mm — strictly homothetic to the
// 50 × 80 × 25 mm workshop mould (×1 = workshop / 4).
mold_width   = 12.5 * mould_size_factor;    // along X axis
mold_height  = 20   * mould_size_factor;    // along Y axis
mold_depth   = 6.25 * mould_size_factor;    // along Z axis
mold_spacing = 3;                           // spacing between the two halves (preview only)
rounded_corners = true;                     // rounded corners reduce warping during printing
edge_radius  = 2    * mould_size_factor;    // radius of the rounded corners

// Key parameters (registration marks between the two halves)
key_size   = 0.75 * mould_size_factor;      // radius of the spherical keys
key_fettle = 0.4;                           // clearance between keys and their holes
key_margin = 1.75 * mould_size_factor;      // distance from the outer edge of the mould

/*************************************************
 Engraving parameters — text (back face) + braille (lateral face)
*************************************************/
// Text engraved on the BACK of each half. The text IS scaled with the mould
// (stays proportional and readable at every size).
text_top_str    = "REMPLACER";              // engraved on the back of the top half
text_bottom_str = "REPLACE";                // engraved on the back of the bottom half
text_size       = 2.25 * mould_size_factor; // letter height (mm) — 6.75 at ×3
text_depth      = 0.4  * mould_size_factor; // engraving depth (mm)
text_font       = "Liberation Sans:style=Bold";
// If the text comes out mirrored after printing, flip the relevant boolean:
text_mirror_top    = false;
text_mirror_bottom = true;

// Braille (standard French) — IN RELIEF on the long lateral face
// (x = -mold_width/2) of the bottom half, centred vertically and along Y.
// The word "remplacer" = 9 cells at the standard Marburg pitch (6 mm).
// Braille dimensions are ABSOLUTE (not scaled with the mould) — this is the
// tactile standard. At ×3, the 6 mm pitch fits within the 60 mm long face.
//   r        e     m       p         l       a   c     e     r
//   1235     15    134     1234      123     1   14    15    1235
braille_word = [
    [1,2,3,5],
    [1,5],
    [1,3,4],
    [1,2,3,4],
    [1,2,3],
    [1],
    [1,4],
    [1,5],
    [1,2,3,5]
];
braille_dot_d      = 1.5;               // dot base diameter at the surface (mm)
braille_dot_h      = 0.75;              // dot height above the face (mm) — Marburg standard ≈ 0.5
braille_dot_dist   = 2.5;               // dot spacing within a cell (Marburg standard)
braille_cell_pitch = 6.0;               // spacing between cells (Marburg standard)

/*************************************************
 Pour channel — aligned on the brainstem
*************************************************/
pour_hole     = 1;                          // 0 = no, 1 = yes
pour_funnel_r = 1.75 * mould_size_factor;   // entry radius (wide), in mm in the mould
pour_neck_r   = 0.6  * mould_size_factor;   // outlet radius (narrow), at the brainstem (mm)

// >>> Points in the STL FRAME — CALIBRATED on this mold_file.stl <<<
//   bs_tip   = tip of the brainstem (caudal-ventral extremity)
//   bs_entry = same oblique axis, extended to exit through the lower face
// (Re-calibrate with show_brain_debug if you change STL.)
bs_tip   = [ -0.3, -25.3,  76.4 ];
bs_entry = [  5.9, -43.1, 128.1 ];

// Debug helpers
show_brain_debug = false;   // true -> brain ALONE + markers, in STL coordinates
debug_tronc = false;        // true -> witness sphere on bs_tip (in the mould)
debug_canal = false;        // true -> channel rendered transparent in the mould (%)

if (show_brain_debug)
    debug_brain();          // <-- to CALIBRATE bs_tip / bs_entry
else
    side_by_side();

/****************************************
 Conical frustum between two 3D points.
 The obliquity follows directly from the vector p2 - p1.
 (cylinder of radius r1 at p1, r2 at p2)
*****************************************/
module cone_between(p1, p2, r1, r2, fn = 48) {
    v = p2 - p1;
    h = norm(v);
    if (h > 0)
        translate(p1)
            rotate([0, acos(v[2]/h), atan2(v[1], v[0])])
                cylinder(h = h, r1 = r1, r2 = r2, $fn = fn);
}

/****************************************
 Pour channel, defined in the brain frame.
 Wrapped in the SAME transformation chain as the STL import so it aims
 straight at the brainstem. The radii are divided by model_scale to cancel
 out the final scale.
*****************************************/
module pour_channel() {
    scale(model_scale)
        translate(model_translate)
            rotate(model_rotate)
                cone_between(bs_entry, bs_tip,
                             pour_funnel_r / model_scale,
                             pour_neck_r   / model_scale);
}
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

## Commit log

2026-06-28 Initial release of REMPLACER mouse brain mould
    Two-part parametric mould for casting agarose mouse brains. Includes 3 STL sizes, alignment script, and bilingual documentation.
    [mould_remplacer.scad]
2026-06-29 Add personal-capacity disclaimer to README
